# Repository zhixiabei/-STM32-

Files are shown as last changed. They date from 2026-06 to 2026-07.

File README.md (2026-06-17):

# 基于STM32的自动售货机

> **Auto Dealer Based on STM32** — 基于 STM32F103C8T6 的智能自动售货机，支持本地按键操控与 OneNET 云端远程控制。







---

## 📖 目录

- [项目简介](#项目简介)
- [功能特性](#功能特性)
- [硬件架构](#硬件架构)
- [系统框图](#系统框图)
- [引脚分配](#引脚分配)
- [固件说明](#固件说明)
- [快速开始](#快速开始)
- [目录结构](#目录结构)
- [物料清单](#物料清单)
- [PCB与Gerber](#pcb与gerber)
- [云平台配置](#云平台配置)
- [注意事项](#注意事项)

---

## 项目简介

本项目实现了一台基于 STM32F103C8T6 的智能自动售货机。用户可以通过 **本地按键** 浏览商品、选择数量并购买，也可以通过 **OneNET 云平台** 远程下发出货指令。OLED 屏幕实时显示商品信息、温湿度等数据，并通过 MQTT 协议将状态上传至云端。

本项目包含完整的 **固件源码**、**电路原理图**、**PCB 设计** 和 **Gerber 生产文件**，可直接复现。

---

## 功能特性

| 功能模块 | 说明 |
|---|---|
| 🛒 **商品售卖** | 支持 4 通道商品（苹果/香蕉/橙子/芒果），本地按键 + 云端远程双模式控制 |
| 📺 **OLED 显示** | 0.96 寸 SSD1306 OLED，128×64 分辨率，中文界面，显示商品列表/库存/价格 |
| 🌡️ **环境监测** | DHT11 温湿度传感器，实时显示温湿度，超阈值蜂鸣器报警（温度>30°C 或湿度>90%） |
| 🌐 **WiFi 联网** | ESP8266-01S 模块，MQTT 协议连接 OneNET Studio 云平台 |
| ☁️ **云端控制** | 支持 OneNET 命令下发远程出货，定时上报库存/温湿度数据 |
| 🔊 **声光指示** | 8 路 LED 指示灯 + 有源蜂鸣器报警 |
| 🛡️ **库存管理** | 实时跟踪商品库存，售罄后自动锁定 |

---

## 硬件架构

- **主控**: STM32F103C8T6（Cortex-M3, 72MHz, 64KB Flash, 20KB SRAM）
- **显示**: 0.96" OLED SSD1306（I2C，4Pin）
- **通信**: ESP8266-01S（UART1, 115200bps，MQTT 协议）
- **传感器**: DHT11 数字温湿度传感器（单总线）
- **驱动**: L298N 双H桥驱动直流减速电机（正转出货）
- **输入**: 6 键独立按键（上翻/下翻/确认/返回/购物车+/购物车-）
- **输出**: 8 路 LED（商品/状态指示）+ 有源蜂鸣器
- **电源**: DC 12V 输入 → LM2596 5V → AMS1117 3.3V 三级供电

### 整机接线总览

> 点击图片可放大查看

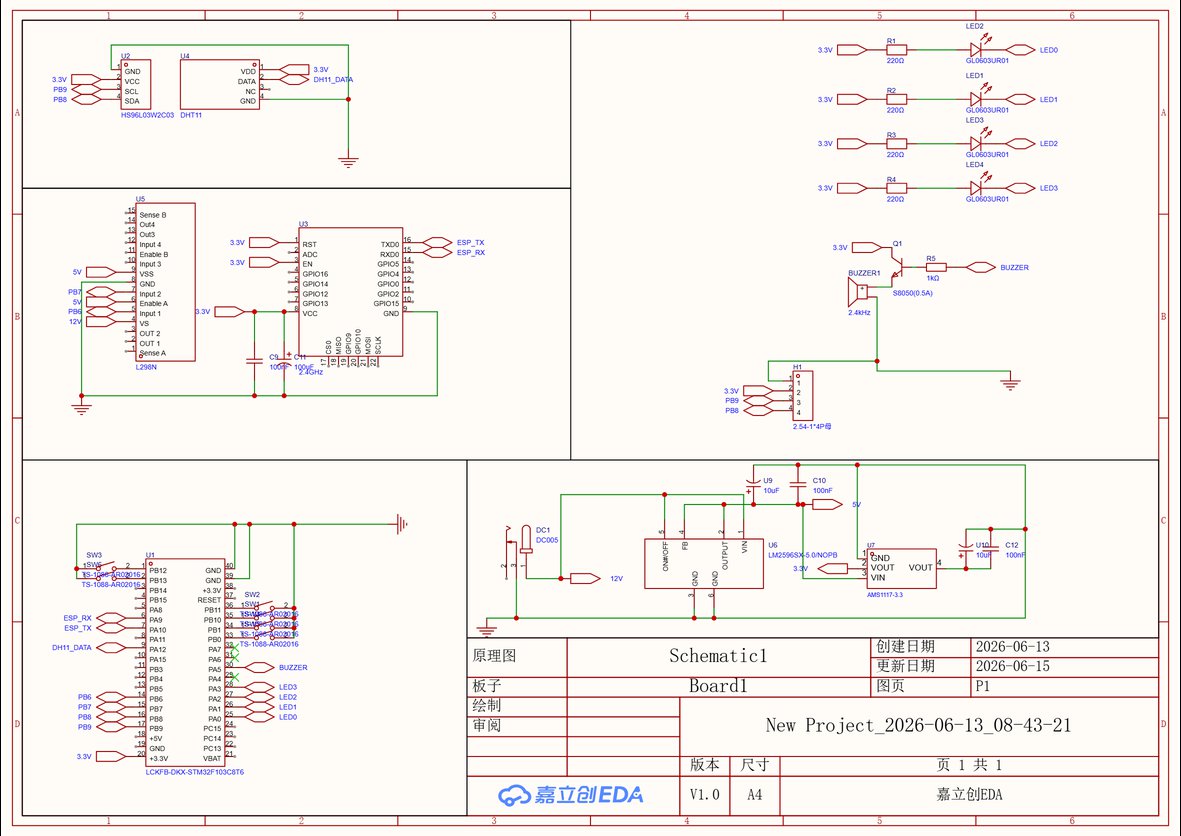
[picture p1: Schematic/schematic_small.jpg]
整机接线总览


---

## 引脚分配

下面是简化的引脚速查表，完整的芯片级引脚对照请参考下方的原理图：

| STM32 引脚 | 功能 | 连接目标 |
|---|---|---|
| PA0 ~ PA7 | GPIO 输出 | LED0 ~ LED7（低电平点亮） |
| PA5 | GPIO 输出 | 蜂鸣器（⚠️ 与 LED5 共用，建议二选一） |
| PA9 | USART1_TX | ESP8266 RXD |
| PA10 | USART1_RX | ESP8266 TXD |
| PA12 | GPIO 输入 | DHT11 DATA（单总线，需 4.7KΩ 上拉） |
| PB0 | GPIO 输入 | 按键 OK（确认） |
| PB1 | GPIO 输入 | 按键 BACK（返回） |
| PB6 | GPIO 输出 | L298N IN1（电机正转） |
| PB7 | GPIO 输出 | L298N IN2（电机反转） |
| PB8 | GPIO 输出 | OLED SCL（软件 I2C 时钟） |
| PB9 | GPIO 输出 | OLED SDA（软件 I2C 数据） |
| PB10 | GPIO 输入 | 按键 CART+（购物车+） |
| PB11 | GPIO 输入 | 按键 CART-（购物车-） |
| PB12 | GPIO 输入 | 按键 UP（上翻） |
| PB13 | GPIO 输入 | 按键 DOWN（下翻） |

> 📖 完整的芯片引脚对照表（含电源/晶振/BOOT/SWD 等全部 48 脚）及原理图设计文档请参阅 **[schematic.md](Auto-Dealer-Based-On-STM32-main/schematic.md)**。

---

## 固件说明

### 开发环境

- **IDE**: Keil MDK 5（或兼容版本）
- **工具链**: Arm Compiler 5 / 6
- **固件库**: STM32F10x 标准外设库 (StdPeriph_Lib)
- **烧录工具**: ST-Link / J-Link（SWD 接口）

### 工程结构

```
Auto-Dealer-Based-On-STM32-main/
├── User/                  # 用户应用层
│   ├── main.c             # 主程序入口，UI 界面与主循环
│   ├── stm32f10x_it.c/h   # 中断服务程序
│   └── stm32f10x_conf.h   # 外设库配置文件
├── Hardware/              # 外设驱动层
│   ├── OLED.c/h           # SSD1306 OLED 驱动（软件 I2C）
│   ├── OLED_Font.h        # 中文字库
│   ├── ESP8266.c/h        # ESP8266 AT 指令 + MQTT 驱动
│   ├── DHT11.c/h          # DHT11 单总线驱动
│   ├── KEY.c/h            # 按键扫描驱动
│   ├── LED.c/h            # LED 驱动
│   ├── BEEP.c/h           # 蜂鸣器驱动
│   ├── ADC.c/h            # ADC 驱动
│   └── Serial.c/h         # 串口驱动
├── System/                # 系统层
│   ├── Delay.c/h          # 延时函数
│   ├── DMA.c/h            # DMA 配置
│   ├── Upload.c/h         # 定时上传 + TIM3 中断
│   ├── i2c.c/h            # 软件 I2C 实现
│   └── main.h             # 系统头文件
├── Start/                 # 启动文件
│   ├── core_cm3.c/h       # Cortex-M3 内核
│   ├── system_stm32f10x.c/h  # 系统时钟配置
│   └── stm32f10x.h        # 外设寄存器定义
├── Library/               # STM32F10x 标准外设库
│   └── stm32f10x_*.c/h    # GPIO/USART/TIM/SPI/I2C/ADC 等
└── 2.1.uvprojx             # Keil MDK 工程文件
```

### 关键逻辑

- **主循环** (`main.c`): 状态机模式，`x` 变量控制界面切换
  - `x=0`: 首页（显示温湿度 + 系统状态）
  - `x=1`: 商品列表页（上下翻选商品）
  - `x=2`: 购物车页（确认数量）
  - `x=4`: 出货中（电机转动 2.5 秒）
- **云端命令**: ESP8266 通过 MQTT 订阅 `DISPENSE_0/2/4/6` 命令，收到后自动进入出货流程
- **定时上报**: TIM3 每 5 秒触发中断 → `DataUpload()` 将温湿度/库存通过 MQTT 上传至 OneNET

---

## 快速开始

### 1. 硬件准备

按照 [原理图文档](Auto-Dealer-Based-On-STM32-main/schematic.md) 中的接线表连接各模块。确保：
- STM32 最小系统板正常工作
- OLED、ESP8266、DHT11 正确接线
- 电源三级供电（12V → 5V → 3.3V）正常

### 2. 固件编译

1. 使用 Keil MDK 打开 `Auto-Dealer-Based-On-STM32-main/2.1.uvprojx`
2. 检查 `ESP8266.c` 中的 WiFi 和 OneNET 配置是否正确
3. 编译工程（Project → Build Target）
4. 通过 SWD 烧录到目标板

### 3. WiFi & OneNET 配置

在 `Hardware/ESP8266.c` 中修改以下参数：

```c
/* WiFi 配置 */
const char* WIFI_SSID     = "你的WiFi名称";
const char* WIFI_PASSWORD = "你的WiFi密码";

/* OneNET Studio MQTT 配置 */
const char* ProductID  = "你的产品ID";
const char* DeviceName = "你的设备名称";
const char* DeviceKey  = "你的设备密钥";
```

### 4. 运行

上电后：
- OLED 显示 "Connect Wi-Fi"，等待 WiFi 连接
- 连接成功后自动连接 OneNET MQTT
- 首页显示温湿度和系统状态
- 通过按键或云端指令操作

### 5. PCB 打板

`Gerber/` 目录包含完整的生产文件，可直接提交给 PCB 厂商（如嘉立创）进行打板。详细说明参见 `Gerber/PCB下单必读.txt`。

---

## 目录结构

```
基于STM32的自动售货机/
├── README.md                              # 项目说明（本文件）
├── .gitignore                             # Git 忽略规则
├── LICENSE                                # 开源协议
├── Auto-Dealer-Based-On-STM32-main/       # 固件源码（Keil MDK 工程）
│   ├── User/                              #   用户层代码
│   ├── Hardware/                          #   外设驱动
│   ├── System/                            #   系统层
│   ├── Start/                             #   启动文件
│   ├── Library/                           #   STM32 标准外设库
│   ├── Objects/                           #   编译输出（含 .hex 固件）
│   ├── Listings/                          #   链接 Map 文件
│   ├── schematic.md                       #   原理图设计文档
│   └── 2.1.uvprojx                        #   Keil 工程文件
├── Schematic/                             # 原理图图片
│   └── schematic_small.jpg                #   原理图预览
├── PCB/                                   # PCB 设计文件
│   ├── New Project_*.epru                 #   立创EDA 工程文件
│   ├── project2.json                      #   工程配置
│   └── IMAGE/                             #   PCB 预览图（待补充）
├── Gerber/                                # PCB 生产文件（可直接打板）
│   ├── Gerber_TopLayer.GTL                #   顶层铜皮
│   ├── Gerber_BottomLayer.GBL             #   底层铜皮
│   ├── Gerber_TopSilkscreenLayer.GTO      #   顶层丝印
│   ├── Gerber_TopSolderMaskLayer.GTS      #   顶层阻焊
│   ├── Gerber_BottomSolderMaskLayer.GBS   #   底层阻焊
│   ├── Gerber_BoardOutlineLayer.GKO       #   板框
│   ├── Gerber_DrillDrawingLayer.GDD       #   钻孔图
│   ├── Drill_PTH_Through.DRL              #   钻孔文件
│   └── PCB下单必读.txt                    #   打板说明
└── Docs/                                  # 文档
    └── BOM_Board1_PCB1.xlsx              #   BOM 物料清单
```

---

## 物料清单

| 类别 | 关键物料 | 数量 | 备注 |
|---|---|---|---|
| 主控 | STM32F103C8T6 最小系统板 | 1 | LQFP-48 |
| 显示 | 0.96" OLED SSD1306 I2C | 1 | 128×64, 蓝色/白色 |
| WiFi | ESP8266-01S | 1 | 8Pin 排针 |
| 传感器 | DHT11 温湿度模块 | 1 | 单总线 |
| 电机驱动 | L298N 模块 | 1 | 双H桥 |
| 电机 | 直流减速电机 12V ~200RPM | 1 | |
| 电源 | LM2596 DC-DC 降压模块 | 1 | 12V→5V |
| 电源 | AMS1117-3.3 LDO | 1 | 5V→3.3V |
| 按键 | 6×6mm 轻触开关 | 6 | |
| LED | 0805 贴片 LED（红/绿/黄） | 8 | 含限流电阻 220Ω |
| 蜂鸣器 | 有源蜂鸣器 3.3V | 1 | |
| 电源 | DC 12V/2A 适配器 | 1 | 5.5×2.1mm |

> 完整 BOM 参见 `Docs/BOM_Board1_PCB1.xlsx`

---

## PCB与Gerber

PCB 使用 **立创EDA** 设计，Gerber 文件已导出，可直接提交打板：

- **Gerber 文件**: `Gerber/` 目录包含所有生产层
- **PCB 工程**: `PCB/` 目录包含立创EDA 工程文件（`.epru`）
- **PCB 预览图**: `PCB/IMAGE/`（待补充 2D/3D 渲染图）

### Gerber 文件清单

| 文件 | 说明 |
|---|---|
| `Gerber_TopLayer.GTL` | 顶层铜皮 |
| `Gerber_BottomLayer.GBL` | 底层铜皮 |
| `Gerber_TopSilkscreenLayer.GTO` | 顶层丝印 |
| `Gerber_BottomSilkscreenLayer.GBO` | 底层丝印 |
| `Gerber_TopSolderMaskLayer.GTS` | 顶层阻焊 |
| `Gerber_BottomSolderMaskLayer.GBS` | 底层阻焊 |
| `Gerber_TopPasteMaskLayer.GTP` | 顶层钢网 |
| `Gerber_BoardOutlineLayer.GKO` | 板框 |
| `Gerber_DrillDrawingLayer.GDD` | 钻孔图 |
| `Drill_PTH_Through.DRL` | 通孔钻孔 |
| `Drill_PTH_Through_Via.DRL` | 过孔钻孔 |

---

## 云平台配置

本项目使用 **中国移动 OneNET Studio** 作为物联网云平台。

### MQTT 主题

| 主题 | 方向 | 说明 |
|---|---|---|
| `$sys/{PID}/{Device}/dp/post/json` | 设备→云 | 数据上报（温湿度/库存） |
| `$sys/{PID}/{Device}/cmd/request/+` | 云→设备 | 命令下发订阅 |

### 上报数据格式 (JSON)

```json
{
  "temp": 25.3,
  "humi": 58.2,
  "Apple": 10,
  "Banana": 8,
  "Orange": 10,
  "Mango": 9
}
```

### 下发命令

| 命令 | 说明 |
|---|---|
| `DISPENSE_0` | 出货：苹果（通道0） |
| `DISPENSE_2` | 出货：香蕉（通道2） |
| `DISPENSE_4` | 出货：橙子（通道4） |
| `DISPENSE_6` | 出货：芒果（通道6） |

---

## 注意事项

1. **PA5 引脚冲突**: PA5 同时驱动 LED5 和蜂鸣器，建议在 PCB 上通过跳线或 0Ω 电阻二选一焊接
2. **ESP8266 供电**: ESP8266 峰值电流约 300mA，AMS1117-3.3 需留足余量，建议在 ESP8266 VCC 旁并联 100μF+100nF 电容
3. **共地**: 所有模块（12V/5V/3.3V）的 GND 必须接在一起
4. **WiFi 凭证**: 发布前请清除 `ESP8266.c` 中的 WiFi 密码和 OneNET 密钥，改为占位符
5. **电机干扰**: 直流电机为强干扰源，电机引线应远离信号线（尤其是 DHT11 单总线和 I2C 线）
6. **I2C 上拉**: 确认 OLED 模块板上是否已集成 I2C 上拉电阻，若无须外加 4.7KΩ×2 至 3.3V
7. **SWD 调试口**: 务必预留 SWDIO(PA13)、SWCLK(PA14)、3.3V、GND 四线调试接口

---

## 许可证

本项目采用 [MIT License](LICENSE) 开源。

---

> **相关文档**: 
> - [原理图设计文档](Auto-Dealer-Based-On-STM32-main/schematic.md)
> - [快速接线参考](Auto-Dealer-Based-On-STM32-main/schematic.md#附录-快速接线表-焊接参考)
> - [BOM 物料清单](Docs/BOM_Board1_PCB1.xlsx)

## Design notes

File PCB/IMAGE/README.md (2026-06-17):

# PCB 预览图

此处应放置 PCB 的 2D/3D 渲染预览图，建议从立创EDA导出以下视角：

- **Top View** — PCB 顶层 3D 视图
- **Bottom View** — PCB 底层 3D 视图
- **Top Silkscreen** — 顶层丝印图

> 在立创EDA中：文件 → 导出 → PNG，选择对应图层即可导出预览图。

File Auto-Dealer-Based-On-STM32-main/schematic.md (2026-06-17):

# 基于STM32的自动售货机 — 原理图设计文档

> **MCU**: STM32F103C8T6 | **固件仓库**: Auto-Dealer-Based-On-STM32  
> **设计工具**: 本原理图适配 立创EDA / Altium Designer / KiCad 均可复现

---

## 目录

1. [系统总体框图](#1-系统总体框图)
2. [STM32F103C8T6 最小系统](#2-stm32f103c8t6-最小系统)
3. [电源电路](#3-电源电路)
4. [OLED 显示接口](#4-oled-显示接口)
5. [ESP8266 WiFi 模块接口](#5-esp8266-wifi-模块接口)
6. [DHT11 温湿度传感器](#6-dht11-温湿度传感器)
7. [按键输入电路](#7-按键输入电路)
8. [LED 指示电路](#8-led-指示电路)
9. [蜂鸣器驱动电路](#9-蜂鸣器驱动电路)
10. [电机驱动电路 (L298N)](#10-电机驱动电路-l298n)
11. [完整引脚对照表](#11-完整引脚对照表)
12. [整机互联拓扑图](#12-整机互联拓扑图)
13. [BOM 物料清单](#13-bom-物料清单)
14. [接线注意事项](#14-接线注意事项)

---

## 1. 系统总体框图

```mermaid
flowchart TB
    subgraph Power["电源系统"]
        DC12V["DC 12V 输入<br/>(适配器/电池)"]
        BUCK5V["LM2596 降压模块<br/>12V → 5V"]
        LDO33["AMS1117-3.3<br/>5V → 3.3V"]
        DC12V --> BUCK5V --> LDO33
    end

    subgraph MCU["主控"]
        STM32["STM32F103C8T6<br/>Cortex-M3, 72MHz<br/>64KB Flash, 20KB SRAM"]
    end

    subgraph Input["输入设备"]
        KEYS["6键独立按键<br/>(上/下/确认/返回/购物车+/购物车-)"]
        DHT11["DHT11<br/>温湿度传感器"]
    end

    subgraph Output["输出设备"]
        OLED["0.96寸 OLED<br/>128x64, I2C, SSD1306"]
        LED8["8路 LED 指示灯<br/>(含蜂鸣器共用)"]
        BUZZER["有源蜂鸣器<br/>3.3V 驱动"]
        MOTOR["直流减速电机<br/>+ L298N 驱动"]
    end

    subgraph Comm["通信"]
        ESP8266["ESP8266-01S<br/>WiFi 模块<br/>连接 OneNet 云平台"]
    end

    LDO33 --> STM32
    BUCK5V --> MOTOR
    LDO33 --> OLED
    LDO33 --> ESP8266
    LDO33 --> DHT11
    LDO33 --> LED8
    LDO33 --> BUZZER

    KEYS -->|"PB0,PB1,PB10~PB13"| STM32
    DHT11 -->|"PA12 (单总线)"| STM32
    STM32 -->|"PB8,PB9 (I2C)"| OLED
    STM32 -->|"PA0~PA7"| LED8
    STM32 -->|"PA5"| BUZZER
    STM32 -->|"PB6,PB7"| MOTOR
    STM32 -->|"PA9,PA10 (UART1)"| ESP8266
```

---

## 2. STM32F103C8T6 最小系统

### 2.1 原理图

```
                          STM32F103C8T6 (LQFP-48)
                    ┌─────────────────────────────────┐
                    │                                 │
               VBAT │1                          48 VDD│──┼── +3.3V
                    │                           47 VSS│──┼── GND
              PC13  │2                          46 PB9│──┼── OLED_SDA (I2C)
         OSC32_IN   │3  PC14                 45 PB8│──┼── OLED_SCL (I2C)
         OSC32_OUT  │4  PC15                 44 PB7│──┼── MOTOR_B
                    │5  PA0  LED0           43 PB6│──┼── MOTOR_A
                    │6  PA1  LED1           42 PB5│
                    │7  PA2  LED2           41 PB4│
                    │8  PA3  LED3           40 PB3│
                    │9  PA4  LED4           39 PB2│
                    │10 PA5  BEEP/LED5      38 PB1│──┼── KEY_BACK
                    │11 PA6  LED6           37 PB0│──┼── KEY_OK
                    │12 PA7  LED7           36 PA15│
           NRST ────│13                    35 PA12│──┼── DHT11_DATA
                    │14 VSS          34 PA11│
              +3.3V │15 VDD          33 PA10│──┼── USART1_RX (ESP TX)
                    │16 PA8            32 PA9│──┼── USART1_TX (ESP RX)
           BOOT0 ── │17 PB15         31 PA8│
           BOOT1 ── │18 PB14         30 PB13│──┼── KEY_DOWN
                    │19 PB13 KEY_DOWN     29 PB12│──┼── KEY_UP
                    │20 PB12 KEY_UP       28 VDD│──┼── +3.3V
                    │21 VSS                      27 VSS│──┼── GND
                    │22 VDD          26 PB11│──┼── KEY_CART-
                    │23 PB10 KEY_CART+     25 PB10│──┼── (reserved)
                    │24 PB11 KEY_CART-               │
                    │                                 │
                    └─────────────────────────────────┘

        晶振电路:                         复位电路:
        ┌─────────────┐                 ┌─────────────┐
        │  OSC_IN  OSC_OUT │                 +3.3V
        │   │        │    │                   │
        │   ├─[8MHz]─┤    │                  [10KΩ]
        │   │        │    │                   │
        │  ─┴─      ─┴─   │              NRST ├──── [100nF] ──── GND
        │ [22pF]   [22pF]  │                   │
        │  ─┬─      ─┬─   │                  ╱ ╲  (复位按键)
        │   │        │    │                 ╱ ○ ╲
        │  GND      GND   │                 ╲   ╱
        └─────────────┘                 ╲ ╱
                                            │
                                           GND
    ```

### 2.2 元件参数

| 元件 | 参数 | 数量 | 说明 |
|---|---|---|---|
| 主控芯片 | STM32F103C8T6 | 1 | LQFP-48 封装 |
| 主晶振 | 8MHz 无源晶振 | 1 | 配 22pF 负载电容 ×2 |
| RTC晶振(可选) | 32.768kHz | 1 | 配 10pF 负载电容 ×2 |
| 复位电阻 | 10KΩ 0603 | 1 | 上拉至 3.3V |
| 复位电容 | 100nF 0603 | 1 | 对地去抖 |
| 复位按键 | 6×6mm 轻触开关 | 1 | 低电平复位 |
| 去耦电容 | 100nF 0603 | 4 | 每个 VDD 引脚各1个 |
| 滤波电容 | 10μF 钽电容 | 1 | VDD 总滤波 |
| BOOT0 跳线 | 2.54mm 排针+跳线帽 | 1 | 默认接 GND |
| BOOT1 跳线 | 2.54mm 排针+跳线帽 | 1 | 默认接 GND |
| SWD调试口 | 4Pin 2.54mm 排针 | 1 | SWDIO/SWCLK/3.3V/GND |

---

## 3. 电源电路

### 3.1 原理图

```
        Power Tree (电源树)
        ═══════════════════════════════════════

        DC 12V 输入                        DC 5V 输出                    DC 3.3V 输出
    (适配器 12V/2A)                  (供 L298N 逻辑 + 外设)        (供 STM32/ESP8266/OLED/DHT11)

    ╔══════════════╗       ╔══════════════╗       ╔══════════════╗
    ║  DC Jack     ║       ║  LM2596      ║       ║  AMS1117-3.3 ║
    ║  5.5×2.1mm   ║──────→║  Buck 模块    ║──────→║  LDO 模块     ║───→ +3.3V
    ║              ║       ║  12V → 5V    ║       ║  5V → 3.3V   ║
    ╚══════════════╝       ╚══════════════╝       ╚══════════════╝
           │                      │                        │
           │ +12V                 │ +5V                    │ +3.3V
           ├──→ L298N 电机电源     ├──→ USB母座(调试)       ├──→ STM32 VDD
           │                      ├──→ 散热风扇(可选)      ├──→ OLED VCC
           │                      │                        ├──→ ESP8266 VCC
           │                      │                        ├──→ DHT11 VCC
           │                      │                        ├──→ LED 阳极电源
           │                      │                        └──→ 蜂鸣器

        ┌─────────────────────────────────────────────────────────┐
        │                   LM2596 模块 (降压)                      │
        │                                                         │
        │   +12V ────┬── LM2596-5.0 ──┬─── +5V                   │
        │            │    IN    OUT   │                            │
        │            │    GND   FB   │                            │
        │            │     │     │    │                            │
        │           ===  100μF   ─┴─ L1 33μH                      │
        │           GND   35V    ─┬─                              │
        │                        ─┴─ 220μF 16V                    │
        │                         │                               │
        │           SS34 续流二极管 (从 OUT 到 GND，反接)           │
        │                                                         │
        └─────────────────────────────────────────────────────────┘

        ┌─────────────────────────────────────────────────────────┐
        │                  AMS1117-3.3 模块 (LDO)                  │
        │                                                         │
        │   +5V ─────┬── AMS1117-3.3 ──┬─── +3.3V                │
        │            │   IN      OUT  │                           │
        │            │   GND(TAB)     │                           │
        │            │     │          │                           │
        │           ===  10μF        === 10μF                     │
        │           GND  钽电容       GND 钽电容                   │
        │            │              │                             │
        │           GND            GND                            │
        └─────────────────────────────────────────────────────────┘

        ┌─────────────────────────────────────────────────────────┐
        │               12V→5V→3.3V 供电汇总                       │
        │                                                         │
        │  【12V 轨】─ L298N 电机驱动 (VMOT，峰值 2A)               │
        │  【5V 轨】 ─ L298N 逻辑供电 (VSS，~50mA)                  │
        │             ─ AMS1117 输入端                             │
        │  【3.3V轨】─ STM32F103C8T6 (~50mA)                       │
        │             ─ ESP8266-01S (峰值 ~300mA，平均 ~80mA)       │
        │             ─ OLED SSD1306 (~20mA)                       │
        │             ─ DHT11 (~2.5mA)                             │
        │             ─ 8×LED (~5mA×8=40mA)                        │
        │             ─ 有源蜂鸣器 (~30mA)                          │
        │                                                         │
        │  3.3V 总电流估算: ~442mA (建议提供 ≥800mA 余量)           │
        │  5V 总电流估算:   ~500mA (建议 LM2596 1A 以上)            │
        └─────────────────────────────────────────────────────────┘
```

### 3.2 元件参数

| 元件 | 参数 | 数量 | 封装 |
|---|---|---|---|
| DC 电源插座 | 5.5×2.1mm DC Jack | 1 | 直插 |
| LM2596 降压模块 | 12V→5V, 3A | 1 | 成品模块 |
| AMS1117-3.3 | 3.3V LDO, 1A | 1 | SOT-223 |
| 输入电容 (12V) | 100μF/35V 铝电解 | 1 | 直插 |
| 输出电容 (5V) | 220μF/16V 铝电解 | 1 | 直插 |
| 输入电容 (AMS1117) | 10μF 钽电容 | 1 | 1206 |
| 输出电容 (AMS1117) | 10μF 钽电容 | 1 | 1206 |
| 续流二极管 | SS34 (肖特基 3A/40V) | 1 | SMC |
| 电源开关 | 自锁开关 KCD1-101 | 1 | 面板安装 |
| 电源指示灯 | 红色 LED + 1KΩ 限流电阻 | 1 | 5mm LED |
| 去耦电容 (3.3V总线) | 100nF 0603 | 6 | 0603 |

---

## 4. OLED 显示接口

### 4.1 原理图

```
              STM32F103C8T6                          0.96" OLED (SSD1306)
              ┌──────────┐                          ┌────────────────┐
              │          │                          │                │
              │     PB8  │──────────────────────────│ SCL            │
              │  (SCL)   │       I2C Clock          │                │
              │     PB9  │──────────────────────────│ SDA            │
              │  (SDA)   │       I2C Data           │                │
              │          │                          │                │
              │          │                          │ VCC ─── +3.3V  │
              │          │                          │ GND ─── GND    │
              │          │                          │                │
              └──────────┘                          └────────────────┘

        I2C 上拉电阻 (如果 OLED 模块板上已有可省略):

                 +3.3V                      +3.3V
                   │                          │
                 [4.7KΩ]                    [4.7KΩ]
                   │                          │
        PB8(SCL)──┼──────── OLED SCL         ┼── PB9(SDA) ── OLED SDA

        OLED 模块规格:
        ┌──────────────────────────────────────────┐
        │  尺寸:      0.96 英寸                      │
        │  分辨率:    128 × 64 像素                  │
        │  驱动芯片:  SSD1306                        │
        │  接口:      I2C (地址 0x3C)                │
        │  工作电压:  3.3V                           │
        │  引脚排列:  VCC/GND/SCL/SDA (4 Pin)        │
        │  颜色:      白色/蓝色双色可选               │
        └──────────────────────────────────────────┘
```

### 4.2 连接

| OLED 模块引脚 | 连接目标 | 备注 |
|---|---|---|
| VCC | +3.3V | |
| GND | GND | |
| SCL | STM32 PB8 | 软件 I2C 时钟 |
| SDA | STM32 PB9 | 软件 I2C 数据 |

> **注**: 代码使用软件 I2C 实现，不使用 STM32 硬件 I2C 外设。上拉电阻通常集成在 OLED 模块 PCB 上，若无则需外加 4.7KΩ ×2。

---

## 5. ESP8266 WiFi 模块接口

### 5.1 原理图

```
              STM32F103C8T6                          ESP8266-01S
              ┌──────────┐                         ┌──────────────┐
              │          │                         │              │
              │     PA9  │──┬──────────────────────│ RXD          │
              │ (TX)     │  │     UART TX          │              │
              │    PA10  │──┼──────────────────────│ TXD          │
              │ (RX)     │  │     UART RX          │              │
              │          │  │                      │              │
              │          │  │                      │ VCC ── +3.3V │
              │          │  │                      │ GND ── GND   │
              │          │  │                      │ CH_PD ── +3.3V│ (使能引脚)
              │          │  │                      │ RST  ── +3.3V │ (通过 10KΩ)
              │          │  │                      │              │
              └──────────┘  │                      └──────────────┘
                            │
        ┌───────────────────┴─────────────────────────────────────┐
        │               电平匹配说明                                │
        │                                                         │
        │  STM32 PA9 (TX)  →  3.3V 电平  →  ESP8266 RXD  ✓ 兼容   │
        │  ESP8266 TXD    →  3.3V 电平  →  STM32 PA10 (RX) ✓ 兼容  │
        │                                                         │
        │  ⚠ ESP8266 峰值电流可达 300mA，3.3V LDO 需足够余量         │
        │  ⚠ ESP8266 CH_PD (EN) 必须接高电平才能工作                 │
        │  ⚠ 建议在 ESP8266 VCC 旁并联 100μF 电解电容 + 100nF 陶瓷   │
        └─────────────────────────────────────────────────────────┘

        ESP8266 电源滤波推荐:

            +3.3V ──┬── 100μF/6.3V ──┬── 100nF ──┬── ESP8266 VCC
                    │    电解电容     │   陶瓷     │
                   GND              GND         GND
```

### 5.2 连接

| ESP8266-01S 引脚 | 连接目标 | 备注 |
|---|---|---|
| VCC | +3.3V | 需 ≥300mA 驱动能力 |
| GND | GND | |
| RXD | STM32 PA9 (USART1_TX) | 115200 波特率 |
| TXD | STM32 PA10 (USART1_RX) | 115200 波特率 |
| CH_PD (EN) | +3.3V (通过 10KΩ 上拉) | 必须拉高 |
| RST | +3.3V (通过 10KΩ 上拉) | 外部复位 |
| GPIO0 | 悬空 (或 10KΩ 上拉) | 低电平=下载模式 |
| GPIO2 | 悬空 (或 10KΩ 上拉) | 上电需高电平 |

---

## 6. DHT11 温湿度传感器

### 6.1 原理图

```
              STM32F103C8T6                            DHT11 模块
              ┌──────────┐                          ┌──────────────┐
              │          │                          │              │
              │    PA12  │──────────────────────────│ DATA         │
              │          │       单总线              │              │
              │          │                          │ VCC ── +3.3V │
              │          │                          │ GND ── GND   │
              │          │                          │              │
              └──────────┘                          └──────────────┘

        上拉电阻 (DHT11 模块板上通常已有):

                           +3.3V
                             │
                           [4.7KΩ ~ 10KΩ]
                             │
              PA12 ──────────┼──────── DHT11 DATA

        DHT11 模块规格:
        ┌──────────────────────────────────────────┐
        │  温度范围:   0 ~ 50°C (精度 ±2°C)          │
        │  湿度范围:   20 ~ 90% RH (精度 ±5%RH)       │
        │  采样周期:   ≥1 秒                         │
        │  接口:       单总线 (One-Wire)              │
        │  工作电压:   3.3V ~ 5V                      │
        │  引脚排列:   VCC/DATA/NC/GND 或 VCC/DATA/GND│
        └──────────────────────────────────────────┘
```

### 6.2 连接

| DHT11 引脚 | 连接目标 | 备注 |
|---|---|---|
| VCC | +3.3V | 兼容 3.3V~5V |
| DATA | STM32 PA12 | 单总线，需 4.7KΩ 上拉 |
| GND | GND | |

---

## 7. 按键输入电路

### 7.1 原理图

```
        6 键独立按键电路 (内部上拉, 按下低电平)

                        按键功能映射:

              上翻 (UP)    下翻 (DOWN)
              ┌─────┐     ┌─────┐
              │ PB12│     │ PB13│
              └──┬──┘     └──┬──┘
                 │            │
          ═══════╪════════════╪═══════
                 │            │
              ┌──┴──┐     ┌──┴──┐     ┌─────┐     ┌─────┐
              │ 上  │     │ 下  │     │确认 │     │返回 │
              │商品 │     │商品 │     │(OK) │     │(BACK)│
              └─────┘     └─────┘     └──┬──┘     └──┬──┘
                                        │            │
                                       PB0          PB1

              商品选择界面:              购物车界面:
              PB12 → 上一商品            PB10 → 数量+1
              PB13 → 下一商品            PB11 → 数量-1
              PB0  → 确认选择            PB0  → 确认结算
              PB1  → 返回首页            (超时自动返回)

        每个按键的电路 (以 PB0 为例):

                        +3.3V
                          │
                    内部上拉 (~40KΩ)
                          │
              ┌───────────┼────── TO STM32 PB0
              │           │
              │     ┌─────┴─────┐
              │     │  10KΩ     │  (可选外部上拉,增强抗干扰)
              │     └─────┬─────┘
              │           │
              │     ┌─────┴─────┐
              │     │     ╱ ╲   │
              │     │    ╱ ○ ╲  │  轻触按键 (6×6mm)
              │     │    ╲   ╱  │
              │     │     ╲ ╱   │
              │     └─────┬─────┘
              │           │
              │          GND
              │
              └──── 消抖电容 100nF (可选,PCB布局时预留)

        6键引脚分配:
        ┌──────────┬──────────┬────────────────────────────┐
        │  按键功能 │ STM32引脚 │  操作界面说明               │
        ├──────────┼──────────┼────────────────────────────┤
        │  上翻     │ PB12     │ 商品选择: 上一个商品         │
        │  下翻     │ PB13     │ 商品选择: 下一个商品         │
        │  确认(OK) │ PB0      │ 选择→确认购买→结算          │
        │  返回     │ PB1      │ 返回上一级 / 首页            │
        │  购物车+  │ PB10     │ 购物车: 同商品数量+1         │
        │  购物车-  │ PB11     │ 购物车: 同商品数量-1         │
        └──────────┴──────────┴────────────────────────────┘
```

### 7.2 元件参数

| 元件 | 参数 | 数量 | 封装 |
|---|---|---|---|
| 轻触按键 | 6×6×5mm, 4脚 | 6 | 直插 |
| 外部上拉电阻(可选) | 10KΩ 0603 | 6 | 0603 |
| 消抖电容(可选) | 100nF 0603 | 6 | 0603 |

> **注**: 代码已启用 STM32 内部上拉 (`GPIO_Mode_IPU`)，硬件上拉电阻非必须，但在工业环境建议保留增强抗干扰。

---

## 8. LED 指示电路

### 8.1 原理图

```
        8路 LED 指示灯 (低电平驱动)

                   +3.3V
                     │
              ┌──────┼──────┬──────┬──────┬──────┬──────┬──────┐
              │      │      │      │      │      │      │      │
             [R]    [R]    [R]    [R]    [R]    [R]    [R]    [R]
           220Ω×8  220Ω   220Ω   220Ω   220Ω   220Ω   220Ω   220Ω
              │      │      │      │      │      │      │      │
             LED    LED    LED    LED    LED    LED    LED    LED
            D0(红) D1(绿) D2(黄) D3(绿) D4(红) D5(黄) D6(红) D7(绿)
              │      │      │      │      │      │      │      │
             PA0    PA1    PA2    PA3    PA4    PA5    PA6    PA7
              │      │      │      │      │      │      │      │
              └──────┴──────┴──────┴──────┴──────┴──────┴──────┘
                               STM32 GPIOA

        单路 LED 电路:
                                             LED电流计算:
                 +3.3V                     ─────────────────
                   │                       ILED = (3.3V - Vf) / R
                 [220Ω]                    = (3.3V - 1.8V) / 220Ω
                   │                       = 1.5V / 220Ω
                  ╱▷  LED                  ≈ 6.8mA
                  ╲▷
                   │
                  PAx (GPIO 低电平点亮)

        LED 功能分配:
        ┌──────┬──────┬──────────────────────────────┐
        │ LED  │ 引脚 │ 用途                         │
        ├──────┼──────┼──────────────────────────────┤
        │ LED0 │ PA0  │ 电源/系统状态指示             │
        │ LED1 │ PA1  │ 商品通道1 状态                │
        │ LED2 │ PA2  │ 商品通道2 状态                │
        │ LED3 │ PA3  │ 商品通道3 状态                │
        │ LED4 │ PA4  │ 商品通道4 状态                │
        │ LED5 │ PA5  │ ⚠ 与蜂鸣器共用,二选一         │
        │ LED6 │ PA6  │ 出货状态指示                  │
        │ LED7 │ PA7  │ WiFi连接状态                  │
        └──────┴──────┴──────────────────────────────┘

        ⚠ PA5 冲突说明:
           PA5 同时被 LED5 和 BEEP 初始化。
           如果同时焊接 LED 和蜂鸣器:
           - 蜂鸣器响时,LED5 也会亮
           - LED5 闪烁时,蜂鸣器可能发出微弱噪音
           建议: 二选一焊接,或通过跳线选择
```

### 8.2 元件参数

| 元件 | 参数 | 数量 | 封装 |
|---|---|---|---|
| LED (红色) | 0805 贴片, Vf≈1.8V | 3 | 0805 |
| LED (绿色) | 0805 贴片, Vf≈2.0V | 3 | 0805 |
| LED (黄色) | 0805 贴片, Vf≈1.9V | 2 | 0805 |
| 限流电阻 | 220Ω 0603 | 8 | 0603 |

---

## 9. 蜂鸣器驱动电路

### 9.1 原理图

```
        有源蜂鸣器驱动 (低电平触发)

        ┌─────────────────────────────────────────────────┐
        │                                                 │
        │    +3.3V                                        │
        │      │                                          │
        │    ┌─┴─┐                                        │
        │    │BEEP│  有源蜂鸣器 (内置振荡器,通直流即响)      │
        │    │   │  工作电压: 3V ~ 5V                      │
        │    └─┬─┘  额定电流: ~30mA                        │
        │      │                                          │
        │    ┌─┴─┐                                        │
        │    │ C │  S8050 NPN 三极管 (开关驱动)             │
        │    └─┬─┘  Ic_max = 500mA                        │
        │      │                                          │
        │     E                                           │
        │      │                                          │
        │     GND                                         │
        │                                                 │
        └─────────────────────────────────────────────────┘

        基极驱动:

                    STM32 PA5 ────[1KΩ]──── B (S8050基极)

        ⚠ PA5 同时驱动 BEEP 和 LED5。由于有源蜂鸣器工作电流 ~30mA,
        而 LED 仅需 ~7mA, 建议优先保证蜂鸣器焊接,LED5 通过跳线可选。

        简化的直接驱动方案 (如果蜂鸣器电流小):

                    PA5 ──── 蜂鸣器 ──── GND

        提示: 代码中 Beep_Init() 将 PA5 配置为推挽输出,
        GPIO_SetBits 关闭蜂鸣器(高电平),GPIO_ResetBits 开启(低电平)。
        蜂鸣器负极接 PA5, 正极接 +3.3V。
```

### 9.2 元件参数

| 元件 | 参数 | 数量 | 封装 |
|---|---|---|---|
| 有源蜂鸣器 | 3.3V 电磁式, ≥85dB | 1 | 直插 12mm |
| NPN 三极管 | S8050 (或 2N3904) | 1 | SOT-23 |
| 基极电阻 | 1KΩ 0603 | 1 | 0603 |
| 续流二极管(可选) | 1N4148 (反向并联蜂鸣器) | 1 | SOD-123 |

---

## 10. 电机驱动电路 (L298N)

### 10.1 原理图

```
        直流电机驱动 — L298N 模块

                     ┌───────────────── L298N 模块 ──────────────────┐
                     │                                               │
        +12V ────────┤ VMOT (电机电源, 12V)                           │
                     │                                               │
        +5V ─────────┤ VSS  (逻辑电源, 5V)   OUT1 ────┬── 直流电机    │
                     │                               │   (减速电机)   │
        GND ─────────┤ GND                  OUT2 ────┘               │
                     │                                               │
        STM32 PB6 ───┤ IN1                                    │      │
        STM32 PB7 ───┤ IN2                                          │
                     │                                               │
        悬空/接GND ──┤ ENA (使能, 跳线帽短接=常使能)                  │
        悬空/接GND ──┤ ENB (未使用)                                   │
                     │                                               │
                     └───────────────────────────────────────────────┘

        电机控制逻辑 (L298N):
        ┌──────┬──────┬────────────────┐
        │ IN1  │ IN2  │  电机状态       │
        │(PB6) │(PB7) │                │
        ├──────┼──────┼────────────────┤
        │  0   │  0   │  停止 (刹车)    │
        │  1   │  0   │  正转 (出货)    │
        │  0   │  1   │  反转           │
        │  1   │  1   │  停止 (刹车)    │
        └──────┴──────┴────────────────┘

        代码中 Motor_Turn() 的逻辑:
        ┌───────────────────────────────────────┐
        │  PB6 = 1  (正转启动)                  │
        │  Delay_ms(2500)  — 电机转动 2.5 秒     │
        │  PB6 = 0  (停止)                      │
        │                                       │
        │  实际使用: 电机正转 2.5 秒推出商品      │
        │  然后停止等待下一次触发                 │
        └───────────────────────────────────────┘
```

### 10.2 连接

| L298N 引脚 | 连接目标 | 备注 |
|---|---|---|
| VMOT | DC +12V | 电机供电, 需 ≥1A |
| VSS | DC +5V | 逻辑供电 |
| GND | GND | 需与STM32共地 |
| IN1 | STM32 PB6 | 电机方向控制1 |
| IN2 | STM32 PB7 | 电机方向控制2 |
| ENA | 跳线帽短接至5V (常使能) | 或接PWM调速 |
| ENB | 未使用/悬空 | |
| OUT1 | 直流电机 + | |
| OUT2 | 直流电机 - | |

### 10.3 元件参数

| 元件 | 参数 | 数量 | 说明 |
|---|---|---|---|
| L298N 驱动模块 | 双H桥, 2A/通道 | 1 | 成品模块 |
| 直流减速电机 | 12V, 100~300 RPM | 1 | 扭力视商品重量而定 |
| 续流二极管 | SS34 (L298N 模块已集成) | - | 模块自带 |
| 电机电源滤波电容 | 100μF/25V 铝电解 | 1 | 电机启动去耦 |

---

## 11. 完整引脚对照表

### 11.1 STM32F103C8T6 → 各外设

```
┌────────┬───────────┬──────────────────────┬─────────┬──────────┐
│ 引脚   │ 端口功能  │ 连接目标             │ 模式    │ 备注     │
├────────┼───────────┼──────────────────────┼─────────┼──────────┤
│ PA0    │ GPIO/ADC0 │ LED0 指示灯           │ 推挽输出 │ 低电平点亮│
│ PA1    │ GPIO/ADC1 │ LED1 指示灯           │ 推挽输出 │ 低电平点亮│
│ PA2    │ GPIO/ADC2 │ LED2 指示灯           │ 推挽输出 │ 低电平点亮│
│ PA3    │ GPIO/ADC3 │ LED3 指示灯           │ 推挽输出 │ 低电平点亮│
│ PA4    │ GPIO      │ LED4 指示灯           │ 推挽输出 │ 低电平点亮│
│ PA5    │ GPIO      │ 蜂鸣器 / LED5         │ 推挽输出 │ ⚠共用冲突│
│ PA6    │ GPIO      │ LED6 指示灯           │ 推挽输出 │ 低电平点亮│
│ PA7    │ GPIO      │ LED7 指示灯           │ 推挽输出 │ 低电平点亮│
│ PA9    │ USART1_TX │ ESP8266 RXD           │ 复用推挽 │ 115200bps│
│ PA10   │ USART1_RX │ ESP8266 TXD           │ 上拉输入 │ 115200bps│
│ PA12   │ GPIO      │ DHT11 DATA            │ 上拉输入 │ 单总线   │
│ PB0    │ GPIO      │ 按键: 确认(OK)        │ 上拉输入 │ 按下=0   │
│ PB1    │ GPIO      │ 按键: 返回(BACK)      │ 上拉输入 │ 按下=0   │
│ PB6    │ GPIO      │ L298N IN1 (电机正转)   │ 推挽输出 │          │
│ PB7    │ GPIO      │ L298N IN2 (电机反转)   │ 推挽输出 │          │
│ PB8    │ GPIO      │ OLED SCL (I2C时钟)    │ 推挽输出 │ 软件I2C  │
│ PB9    │ GPIO      │ OLED SDA (I2C数据)    │ 推挽输出 │ 软件I2C  │
│ PB10   │ GPIO      │ 按键: 购物车+         │ 上拉输入 │ 按下=0   │
│ PB11   │ GPIO      │ 按键: 购物车-         │ 上拉输入 │ 按下=0   │
│ PB12   │ GPIO      │ 按键: 上翻 (UP)       │ 上拉输入 │ 按下=0   │
│ PB13   │ GPIO      │ 按键: 下翻 (DOWN)     │ 上拉输入 │ 按下=0   │
├────────┼───────────┼──────────────────────┼─────────┼──────────┤
│ NRST   │ RST       │ 复位电路              │         │          │
│ BOOT0  │ BOOT      │ GND (正常模式)        │         │          │
│ BOOT1  │ BOOT      │ GND (正常模式)        │         │          │
│ OSC_IN │ HSE       │ 8MHz 晶振             │         │          │
│ OSC_OUT│ HSE       │ 8MHz 晶振             │         │          │
│ VDD×4  │ PWR       │ +3.3V                 │         │ 各配100nF│
│ VSS×4  │ PWR       │ GND                   │         │          │
└────────┴───────────┴──────────────────────┴─────────┴──────────┘
```

### 11.2 未使用引脚处理

```
┌─────────┬────────────────────────────────┐
│ 引脚    │ 处理方式                        │
├─────────┼────────────────────────────────┤
│ PA8     │ 悬空 (或 10KΩ 下拉)             │
│ PA11    │ 悬空                            │
│ PA13    │ SWDIO (调试口,预留)             │
│ PA14    │ SWCLK (调试口,预留)             │
│ PA15    │ 悬空                            │
│ PB2     │ 悬空                            │
│ PB3     │ 悬空 (或预留 JTAG)              │
│ PB4     │ 悬空 (或预留 JTAG)              │
│ PB5     │ 悬空                            │
│ PB14    │ 悬空                            │
│ PB15    │ 悬空                            │
│ PC13    │ 悬空 (或接LED,注意电流限制)      │
│ PC14    │ 悬空 (或 RTC 晶振)              │
│ PC15    │ 悬空 (或 RTC 晶振)              │
└─────────┴────────────────────────────────┘
```

---

## 12. 整机互联拓扑图

```
                         整机接线总览
    ═══════════════════════════════════════════════════════════

                         ┌─────────────────────┐
                    ┌────┤   DC 12V 电源适配器   │
                    │    └─────────────────────┘
                    │              │
                    │         ┌────┴────┐
                    │         │  开关    │
                    │         └────┬────┘
                    │              │
              ┌─────┴──────┐  ┌───┴──────┐
              │  LM2596    │  │  L298N   │
              │  12V→5V    │  │  电机驱动  │
              └─────┬──────┘  └──┬───┬───┘
                    │            │   │
              ┌─────┴──────┐   OUT1 OUT2
              │  AMS1117   │     │   │
              │  5V→3.3V   │   ┌─┴───┴─┐
              └─────┬──────┘   │ 直流  │
                    │          │ 电机  │
           +3.3V 总线          └───────┘
              │
    ┌─────────┼─────────┬─────────┬─────────┬─────────┐
    │         │         │         │         │         │
 ┌──┴──┐  ┌──┴──┐  ┌──┴──┐  ┌──┴──┐  ┌──┴──┐  ┌──┴──┐
 │8LED │  │蜂鸣器│  │OLED │  │ESP  │  │DHT11│  │按键 │
 │模块 │  │     │  │0.96"│  │8266 │  │传感器│  │×6   │
 └──┬──┘  └──┬──┘  └──┬──┘  └──┬──┘  └──┬──┘  └──┬──┘
    │        │        │        │        │        │
    └────────┼────────┼────────┼────────┼────────┘
             │        │        │        │
        PA0~PA7  PA5   PB8,PB9 PA9,PA10 PA12  PB0,PB1,PB10~PB13
             │        │        │        │        │
             └────────┴────────┴────────┴────────┘
                            │
                   ┌────────┴────────┐
                   │ STM32F103C8T6    │
                   │ (最小系统板)      │
                   └─────────────────┘
```

---

## 13. BOM 物料清单

### 13.1 核心元件

| 序号 | 元件 | 型号/参数 | 数量 | 封装 | 备注 |
|---|---|---|---|---|---|
| 1 | MCU | STM32F103C8T6 | 1 | LQFP-48 | 或最小系统板 |
| 2 | OLED 显示屏 | 0.96寸 SSD1306 I2C | 1 | 模块 | 4Pin 蓝色/白色 |
| 3 | WiFi 模块 | ESP8266-01S | 1 | 模块 | 8Pin 排针 |
| 4 | 温湿度传感器 | DHT11 | 1 | 模块 | 3Pin/4Pin |
| 5 | 电机驱动 | L298N 模块 | 1 | 模块 | 双H桥 |
| 6 | 直流减速电机 | 12V 200RPM | 1 | - | 带减速箱 |

### 13.2 电源

| 序号 | 元件 | 型号/参数 | 数量 | 封装 | 备注 |
|---|---|---|---|---|---|
| 7 | 降压模块 | LM2596 DC-DC 12V→5V 3A | 1 | 模块 | 成品模块 |
| 8 | LDO | AMS1117-3.3 SOT-223 | 1 | SOT-223 | 或集成于最小系统板 |
| 9 | DC 电源插座 | DC-005 5.5×2.1mm | 1 | 直插 | 母座 |
| 10 | 12V 电源适配器 | 12V/2A | 1 | - | DC 5.5×2.1mm 公头 |
| 11 | 电源开关 | KCD1-101 船型开关 | 1 | 面板 | 自锁 |
| 12 | 电解电容 | 100μF/35V | 1 | 直插 8mm | 输入滤波 |
| 13 | 电解电容 | 220μF/16V | 1 | 直插 8mm | 输出滤波 |
| 14 | 电解电容 | 100μF/6.3V | 1 | 直插 6mm | ESP8266 去耦 |
| 15 | 钽电容 | 10μF/16V | 2 | 1206 | AMS1117 输入/输出 |
| 16 | 肖特基二极管 | SS34 | 1 | SMC | 续流 |
| 17 | 陶瓷电容 | 100nF | 10 | 0603 | 各处去耦 |

### 13.3 输入/输出

| 序号 | 元件 | 型号/参数 | 数量 | 封装 | 备注 |
|---|---|---|---|---|---|
| 18 | 轻触按键 | 6×6×5mm | 6 | 直插 | PB0/1/10/11/12/13 |
| 19 | LED 红色 | 0805 Vf=1.8V | 3 | 0805 | |
| 20 | LED 绿色 | 0805 Vf=2.0V | 3 | 0805 | |
| 21 | LED 黄色 | 0805 Vf=1.9V | 2 | 0805 | |
| 22 | 限流电阻 | 220Ω ±5% | 8 | 0603 | LED 限流 |
| 23 | 有源蜂鸣器 | 3.3V ≥85dB | 1 | 直插 12mm | |
| 24 | NPN 三极管 | S8050 | 1 | SOT-23 | 蜂鸣器驱动 |

### 13.4 无源元件

| 序号 | 元件 | 型号/参数 | 数量 | 封装 | 备注 |
|---|---|---|---|---|---|
| 25 | 8MHz 无源晶振 | ±20ppm | 1 | 49S 或 3225 | |
| 26 | 22pF 电容 | NPO/COG | 2 | 0603 | 晶振负载电容 |
| 27 | 10KΩ 电阻 | ±5% | 8 | 0603 | 上拉/复位/BOOT |
| 28 | 1KΩ 电阻 | ±5% | 1 | 0603 | 蜂鸣器基极 |
| 29 | 4.7KΩ 电阻 | ±5% | 2 | 0603 | I2C上拉(备用) |
| 30 | 排针 | 2.54mm 单排 | 若干 | - | 模块连接 |
| 31 | 跳线帽 | 2.54mm | 3 | - | BOOT/EAN |
| 32 | 杜邦线 | 母对母 20cm | 30+ | - | 模块互联 |

---

## 14. 接线注意事项

### 14.1 电源

1. **12V 与 5V/3.3V 隔离**: 12V 仅供给 L298N 电机驱动和 LM2596 输入端，不要直接接入 STM32 或 ESP8266。
2. **ESP8266 供电**: ESP8266 瞬时电流可达 300mA, AMS1117-3.3 需提供足够余量。建议在 ESP8266 VCC 引脚旁并联 100μF 电解电容 + 100nF 陶瓷电容。
3. **共地**: 所有模块的 GND 必须连接在一起（12V、5V、3.3V 的 GND 共地）。
4. **上电顺序**: 先上电 12V → LM2596 输出 5V → AMS1117 输出 3.3V。断电：先断 12V。

### 14.2 信号

5. **PA5 冲突处理**: PA5 同时用于 LED5 和蜂鸣器。建议在 PCB 设计时通过 0Ω 电阻或跳线二选一：
   - 短接 R_BEEP → 蜂鸣器功能
   - 短接 R_LED5 → LED5 功能
   - 或直接优先焊接蜂鸣器（本项目核心报警功能）
6. **I2C 上拉**: 确认 OLED 模块板上是否有 I2C 上拉电阻。如无，需在 PB8(SCL) 和 PB9(SDA) 各加 4.7KΩ 上拉至 3.3V。
7. **按键消抖**: 代码中已实现 20ms 软件消抖。硬件上如需增强抗干扰，每个按键并联 100nF 电容到 GND。
8. **UART 连接**: STM32 TX(PA9) → ESP8266 RX, STM32 RX(PA10) → ESP8266 TX，注意**交叉连接**（非直连）。

### 14.3 布局

9. **散热**: L298N 模块工作时会发热，建议安装在通风良好处。大电流工作时需加装散热片。
10. **天线区域**: ESP8266 模块的 PCB 天线区域不要覆铜，远离金属物体和大面积 GND 铺铜，以保证 WiFi 信号。
11. **电机干扰**: 直流电机是强干扰源，电机引线应远离信号线（特别是 DHT11 单总线和 I2C 线）。电机两端建议并联 104 瓷片电容吸收火花干扰。
12. **SWD 调试口**: 务必预留 SWDIO(PA13)、SWCLK(PA14)、3.3V、GND 四个调试引脚。

---

## 附录: 快速接线表 (焊接参考)

```
STM32 引脚  ────  目标模块引脚
══════════════════════════════════════

PA0  ──── LED0 (经 220Ω → 3.3V)
PA1  ──── LED1 (经 220Ω → 3.3V)
PA2  ──── LED2 (经 220Ω → 3.3V)
PA3  ──── LED3 (经 220Ω → 3.3V)
PA4  ──── LED4 (经 220Ω → 3.3V)
PA5  ──── 蜂鸣器基极 (经 1KΩ → S8050 B极)
            S8050 C极 ← 蜂鸣器 ← 3.3V
            S8050 E极 → GND
PA6  ──── LED6 (经 220Ω → 3.3V)
PA7  ──── LED7 (经 220Ω → 3.3V)
PA9  ──── ESP8266 RXD
PA10 ──── ESP8266 TXD
PA12 ──── DHT11 DATA (另加 4.7KΩ 上拉至 3.3V)
PB0  ──── 按键 OK → GND
PB1  ──── 按键 BACK → GND
PB6  ──── L298N IN1
PB7  ──── L298N IN2
PB8  ──── OLED SCL
PB9  ──── OLED SDA
PB10 ──── 按键 CART+ → GND
PB11 ──── 按键 CART- → GND
PB12 ──── 按键 UP → GND
PB13 ──── 按键 DOWN → GND

3.3V  ──── OLED VCC, ESP8266 VCC/CH_PD, DHT11 VCC
5V   ──── L298N VSS (逻辑供电)
12V  ──── L298N VMOT (电机供电)
GND  ──── 所有模块 GND (共地!)
```

---

> **文档版本**: v1.0  
> **最后更新**: 2026-06-13  
> **对应固件**: Auto-Dealer-Based-On-STM32 (Keil MDK, STM32F10x 标准外设库)

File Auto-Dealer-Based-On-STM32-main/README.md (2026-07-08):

# Auto Dealer Based ON STM32
基于STM32的自动售货机

## 2026-07-07 更新

适配国产STM32F103C8T6芯片，修复烧录、时钟、串口、延时等硬件兼容问题；适配有源蜂鸣器；WiFi/MQTT连接调通，已接入OneNET平台。

## 2026-07-08 更新

新增手机Web下单界面 (`web/mobile.html`)，可通过手机浏览器远程下单。

### 📱 手机下单 — 使用方法

**① 推荐：Python HTTP 服务**
```bash
cd web
python -m http.server 8080
```
手机连接**同一 WiFi**，浏览器打开：`http://<电脑IP>:8080/mobile.html`

**② 直接打开**
将 `web/mobile.html` 发送到手机，用浏览器直接打开即可。

**③ 部署到静态托管**
上传到 GitHub Pages / Netlify 等平台，手机浏览器随时访问。

### ⚙ 配置
页面右下角点 ⚙ 按钮可配置 OneNET 连接参数（已预填项目默认值）。

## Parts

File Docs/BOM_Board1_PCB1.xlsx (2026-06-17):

No. | Quantity | Comment | Designator | Footprint | Value | Manufacturer Part | Manufacturer | Supplier Part | Supplier
1 | 1 | 2.4kHz | BUZZER1 | BUZ-TH_BD12.0-P7.60-D0.6-FD | 2.4kHz | TMB12A05 | 华能 | C96093 | LCSC
2 | 3 | 100nF | C9,C10,C12 | C0603 | 100nF | CL10B104KB8NNNC | SAMSUNG(三星) | C1591 | LCSC
3 | 1 | 100uF | C11 | CAP-SMD_BD5.0-L5.3-W5.3-LS6.0-FD-H5.4 | 100uF | RVT6.3V100M5X5 | JIERR(捷而瑞) | C49233126 | LCSC
4 | 1 | DC005 | DC1 | DC-IN-TH_DC005 |  | DC005 | SHOU HAN(首韩) | C431533 | LCSC
5 | 4 | GL0603UR01 | LED1,LED2,LED3,LED4 | LED0603-FD |  | GL0603UR01 | Guiguang light(桂光光电) | C51933292 | LCSC
6 | 1 | S8050(0.5A) | Q1 | SOT-23-3_L2.9-W1.3-P1.90-LS2.4-BR |  | S8050(0.5A) | EIC | C3014350 | LCSC
7 | 4 | 220Ω | R1,R2,R3,R4 | R0603 | 220Ω | FRC0603J221 TS | FOJAN(富捷) | C2907127 | LCSC
8 | 1 | 1kΩ | R5 | R0603 | 1kΩ | RT0603BRD071KL | YAGEO(国巨) | C110776 | LCSC
9 | 6 | TS-1088-AR02016 | SW1,SW2,SW3,SW4,SW5,SW6 | SW-SMD_L3.9-W3.0-P4.45 |  | TS-1088-AR02016 | XUNPU(讯普) | C720477 | LCSC
10 | 1 | LCKFB-DKX-STM32F103C8T6 | U1 | CONN-TH_L53.3-W22.9_STM32F103C8T6-CARD |  | LCKFB-DKX-STM32F103C8T6 | 立创开发板 | C22396880 | LCSC
11 | 1 | HS96L03W2C03 | U2 | OLED-TH_L27.8-W27.2-P2.54_C9900033791 |  | HS96L03W2C03 | HS(汉昇) | C5248080 | LCSC
12 | 1 | 2.4GHz | U3 | WIFIM-SMD_ESP-12F-ESP8266MOD | 2.4GHz | ESP-12F(ESP8266MOD) | Ai-Thinker(安信可) | C82891 | LCSC
13 | 1 | DHT11 | U4 | SENSOR-TH_DHT11 |  | DHT11 | 广州奥松 | C117051 | LCSC
14 | 1 | L298N | U5 | MULTIWATT-15_L19.6-W5.0-P1.27-L |  | L298N | ST(意法半导体) | C19922 | LCSC
15 | 1 | LM2596SX-5.0/NOPB | U6 | TO-263-5_L10.2-W8.9-P1.70-TL |  | LM2596SX-5.0/NOPB | TI(德州仪器) | C10002 | LCSC
16 | 1 | AMS1117-3.3 | U7 | SOT-223-3_L6.5-W3.4-P2.30-LS7.0-BR |  | AMS1117-3.3 | Advanced Monolithic Systems | C6186 | LCSC
17 | 2 | 10uF | U9,U10 | CAP-SMD_L3.2-W1.6 | 10uF | TMCMA1C106KTRF | VISHAY(威世) | C4988312 | LCSC

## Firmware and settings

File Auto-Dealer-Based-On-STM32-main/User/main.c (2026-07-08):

#include "stm32f10x.h"
#include "OLED.h"
#include "ESP8266.h"
#include "Serial.h"
#include "DHT11.h"
#include "LED.h"
#include "KEY.h"
#include "BEEP.h"
#include "Upload.h"
#include <string.h>
#include <stdio.h>

/* DHT11 全局变量（定义在 DHT11.c） */
extern u8 humi, temp, dechumi, dectemp;

/* ---- 商品数据 ---- */
/* inventory/price: 8 个槽，偶数索引=商品 */
u8 inventory[16] = {10,0, 10,0, 10,0, 10,0,  9,0, 10,0, 10,0, 10,0};
u8 price[16]     = { 2,0,  1,0,  2,0,  3,0,  4,0,  1,0,  1,0,  4,0};

/* ---- 保存库存到 Flash（每次变更后调用）---- */
static void save_inventory(void)
{
    FlashStore_Save(inventory, price);
}

/* ---- 加载库存：优先从 Flash 读取，失败则用默认值 ---- */
static void load_inventory(void)
{
    if (!FlashStore_Load(inventory, price))
    {
        /* Flash 为空或损坏，写入默认值 */
        FlashStore_Save(inventory, price);
    }
}

/* ---- 延时（约等于 ms）---- */
static void dms(volatile u32 ms)
{
    while (ms--) { volatile u32 n = 2000; while (n--) __NOP(); }
}

/* ---- OLED 快捷显示 ---- */
static void show(const char* l1, const char* l2)
{
    OLED_Clear();
    OLED_ShowString(0, 0,  (u8*)l1, 16, 1);
    OLED_ShowString(0, 16, (u8*)l2, 16, 1);
    OLED_Refresh();
}

/* ---- 错误死循环 ---- */
static void die(const char* m)
{
    show("FAIL", m);
    while (1) { __NOP(); }
}

/* 商品名 */
static const char* names[] = {"Apple","Banana","Orange","Mango"};

int main(void)
{
    /* ---- 状态变量 ---- */
    int8_t  page    = 0;    /* 0=主页 1=选商品 2=选数量 4=出货 */
    int8_t  prev    = -1;   /* 上一页，用于判断刷新 */
    int8_t  sel     = 0;    /* 当前选中商品索引 (0,2,4,6,8,10,12,14) */
    int8_t  cnt     = 0;    /* 购买数量 */
    int8_t  remote  = 0;    /* 0=本地按键出货 1=云端远程出货（需回复服务调用） */
    u8      i;
    u16     tick = 0;
    char    buf[32], json[320];

    /* ---- 初始化硬件 ---- */
    OLED_Init();
    OLED_Clear();
    OLED_ShowString(0, 0, "Vending...", 16, 1);
    OLED_Refresh();

    /* 从 Flash 恢复上次的库存数据 */
    load_inventory();

    Key_Init();
    LED_Init();
    DHT11_Init();
    Mortor_Init();
    Beep_Init();

    /* ---- WiFi + MQTT ---- */
    show("WiFi", "init...");
    {
        int r = ESP8266_Init();
        if (r <= 0) {
            sprintf(buf, "ERR=%d", r);
            die(buf);
        }
    }

    show("WiFi+MQTT", "OK!");
    dms(5000);  /* 等 TCP/IP 栈就绪 */

    /* 定时上传 */
    TIM3IT_Init();

    /* 初始化 LED 状态：有货的通道亮灯 */
    LED_UpdateAll(inventory);

    /* ======== 主循环 ======== */
    while (1)
    {
        tick++;

        /* ---- 传感器（关串口中断，防 DHT11 时序被干扰）---- */
        if (tick % 20 == 0) {
            USART_ITConfig(USART1, USART_IT_RXNE, DISABLE);
            DHT11_Read_data((u8*)&humi, (u8*)&temp, &dechumi, &dectemp);
            USART_ITConfig(USART1, USART_IT_RXNE, ENABLE);
        }

        /* ---- 告警：高温 / 高湿 ---- */
        if (temp > 30 || humi > 90)
            BEEP_Alert();

        /* ---- 云端命令 ---- */
        {
            int8_t cmd = ESP8266_CheckCmd();
            if (cmd != -1)
            {
                if (page == 0)
                {
                    if (inventory[cmd] > 0) {
                        sel = cmd;
                        cnt = 1;
                        remote = 1;             /* 遥控出货，需回报结果 */
                        page = 4;
                    } else {
                        /* 库存为零，回复服务调用失败 */
                        ESP8266_ServiceReply(1);
                    }
                }
                else
                {
                    /* 设备忙，无法处理，清除待回复 ID */
                    ESP8266_ClearPendingSvc();
                }
            }
            else
            {
                /* 库存改写: SET_X_N  e.g. SET_0_15 */
                u8 new_qty;
                int8_t idx = ESP8266_ParseInventory(&new_qty);
                if (idx >= 0 && idx < 16) {
                    inventory[idx] = new_qty;
                    LED_UpdateAll(inventory);   /* 云端改库存后刷新 LED */
                    save_inventory();           /* 持久化到 Flash */
                }
                /* OneNET 属性设置: {"params":{"Banana":10}} */
                else if (ESP8266_HandlePropertySet(inventory)) {
                    LED_UpdateAll(inventory);
                    save_inventory();
                }
            }
        }

        /* ---- 按键处理 ---- */
        /* PB12: 上一个 */
        if (GPIO_ReadInputDataBit(GPIOB, GPIO_Pin_12) == 0)
        {
            dms(20); while (GPIO_ReadInputDataBit(GPIOB, GPIO_Pin_12) == 0);
            if (page == 1) { sel += 2; if (sel > 14) sel = 0; }
        }
        /* PB13: 下一个 */
        if (GPIO_ReadInputDataBit(GPIOB, GPIO_Pin_13) == 0)
        {
            dms(20); while (GPIO_ReadInputDataBit(GPIOB, GPIO_Pin_13) == 0);
            if (page == 1) { sel -= 2; if (sel < 0) sel = 14; }
        }
        /* PB1: 返回 / 进入选择 */
        if (GPIO_ReadInputDataBit(GPIOB, GPIO_Pin_1) == 0)
        {
            dms(20); while (GPIO_ReadInputDataBit(GPIOB, GPIO_Pin_1) == 0);
            if (page == 0)      { page = 1; sel = 0; }      /* 进入选择 */
            else if (page == 1) { page = 0; }                /* 返回主页 */
            else if (page == 2) { page = 1; cnt = 0; }       /* 返回选商品 */
        }
        /* PB0: 确认 */
        if (GPIO_ReadInputDataBit(GPIOB, GPIO_Pin_0) == 0)
        {
            dms(20); while (GPIO_ReadInputDataBit(GPIOB, GPIO_Pin_0) == 0);
            if (page == 1 && inventory[sel] > 0)
                { page = 2; cnt = 1; }                       /* 进入选数量 */
            else if (page == 2 && cnt > 0)
                { page = 4; }                                /* 确认购买 */
        }
        /* PB11: 减 */
        if (GPIO_ReadInputDataBit(GPIOB, GPIO_Pin_11) == 0)
        {
            dms(20); while (GPIO_ReadInputDataBit(GPIOB, GPIO_Pin_11) == 0);
            if (page == 2) { if (--cnt < 1) cnt = 1; }
        }
        /* PB10: 加 */
        if (GPIO_ReadInputDataBit(GPIOB, GPIO_Pin_10) == 0)
        {
            dms(20); while (GPIO_ReadInputDataBit(GPIOB, GPIO_Pin_10) == 0);
            if (page == 2 && cnt < inventory[sel]) cnt++;
        }

        /* ---- 界面渲染（仅页面切换时全刷新）---- */
        if (page != prev) {
            prev = page;
            OLED_Clear();

            if (page == 0)
            {
                OLED_ShowString(0,  0, "Temp:",   16, 1);
                OLED_ShowString(0, 16, "Humi:",   16, 1);
                OLED_ShowString(0, 32, "Press K1", 16, 1);
                OLED_ShowString(0, 48, "to buy",   16, 1);
            }
            else if (page == 1)
            {
                /* 商品列表页 —— 只画静态标签 */
            }
            else if (page == 2)
            {
                OLED_ShowString(0,  0, "Item:",   16, 1);
                OLED_ShowString(0, 16, "Count:",  16, 1);
                OLED_ShowString(0, 32, "Total $", 16, 1);
                OLED_ShowString(0, 48, "K0=OK K1=Back", 16, 1);
            }
            else if (page == 4)
            {
                OLED_ShowString(0,  0, "Dispensing...", 16, 1);
                OLED_Refresh();

                /* 1. 先扣库存 + 持久化（业务逻辑不应依赖硬件） */
                inventory[sel] -= cnt;
                LED_UpdateAll(inventory);
                save_inventory();
                upload = 1;              /* 立即上传最新库存到 OneNET */

                /* 2. 云端远程出货（暂不回复服务调用，避免 tcp_send 干扰 MQTT 上传链路） */
                if (remote) {
                    /* ESP8266_ServiceReply(0);  —— 暂屏蔽，防止破坏 MQTT 连接 */
                    remote = 0;
                }

                /* 3. 最后转动电机（硬件动作，放最后不影响业务逻辑） */
                Mortor_Turn();

                page = 0;
                sel  = 0;
                cnt  = 0;
                prev = -1;  /* 强制下次全刷新 */
            }
        }

        /* 动态数据更新（每次循环都刷新，不清屏） */
        if (page == 0) {
            OLED_ShowNum(48, 0,  temp, 2, 16, 1);
            OLED_ShowString(64, 0, "C", 16, 1);
            OLED_ShowNum(48, 16, humi, 2, 16, 1);
            OLED_ShowString(64,16, "%", 16, 1);
        }
        else if (page == 1) {
            for (i = 0; i < 4; i++) {
                u8 idx = i * 2, row = i * 16;
                u8 hl  = (idx == sel) ? 0 : 1;
                char line[17];
                int j, k = 0;
                /* 手工拼字符串 —— MicroLIB 不支持 %-8s */
                {
                    const char* s = names[i];
                    while (*s) line[k++] = *s++;
                }
                while (k < 9)  line[k++] = ' ';
                line[k++] = '$';
                line[k++] = '0' + price[idx];
                line[k++] = ' ';
                line[k++] = 'x';
                {
                    u8 q = inventory[idx];
                    if (q >= 10) { line[k++] = '0' + q/10; line[k++] = '0' + q%10; }
                    else         { line[k++] = '0' + q;    line[k++] = ' '; }
                }
                while (k < 16) line[k++] = ' ';
                line[16] = '\0';
                OLED_ShowString(0, row, (u8*)line, 16, hl);
            }
        }
        else if (page == 2) {
            OLED_ShowNum(48, 0,  sel,               2, 16, 1);
            OLED_ShowNum(56,16,  cnt,               2, 16, 1);
            OLED_ShowNum(64,32,  cnt * price[sel],  2, 16, 1);
        }

        /* ---- 定时上传数据到 OneNET ---- */
        if (upload == 1)
        {
            upload = 0;
            sprintf(json,
                "{\"id\":\"0\",\"version\":\"1.0\",\"params\":{"
                "\"temp\":{\"value\":%d},"
                "\"humi\":{\"value\":%d},"
                "\"Apple\":{\"value\":%d},"
                "\"Banana\":{\"value\":%d},"
                "\"Orange\":{\"value\":%d},"
                "\"Mango\":{\"value\":%d}"
                "}}",
                (int)temp, (int)humi,
                (int)inventory[0], (int)inventory[2],
                (int)inventory[4], (int)inventory[6]);

            ESP8266_UploadData(json);
        }

        OLED_Refresh();
        dms(50);  /* 主循环 ~20Hz */
    }
}

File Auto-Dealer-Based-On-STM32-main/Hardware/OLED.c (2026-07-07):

#include "stm32f10x.h"                  // Device header
#include "OLED.h"
#include "stdlib.h"
#include "OLED_Font.h"
#include "Delay.h"
#include "math.h"
#include "string.h"

u8 OLED_GRAM[144][8];

//反显函数
void OLED_ColorTurn(u8 i)
{
	if(i==0)
		{
			OLED_WR_Byte(0xA6,OLED_CMD);//正常显示
		}
	if(i==1)
		{
			OLED_WR_Byte(0xA7,OLED_CMD);//反色显示
		}
}

//屏幕旋转180度
void OLED_DisplayTurn(u8 i)
{
	if(i==0)
		{
			OLED_WR_Byte(0xC8,OLED_CMD);//正常显示
			OLED_WR_Byte(0xA1,OLED_CMD);
		}
	if(i==1)
		{
			OLED_WR_Byte(0xC0,OLED_CMD);//反转显示
			OLED_WR_Byte(0xA0,OLED_CMD);
		}
}

//延时
void IIC_delay(void)
{
	volatile u8 t = 8;    // 开漏模式，延时加长保证信号稳定
	while (t--) { __NOP(); }
}

//起始信号
void I2C_Start(void)
{
	OLED_SDA_Set();
	OLED_SCL_Set();
	IIC_delay();
	OLED_SDA_Clr();
	IIC_delay();
	OLED_SCL_Clr();
	IIC_delay();
}

//结束信号
void I2C_Stop(void)
{
	OLED_SDA_Clr();
	OLED_SCL_Set();
	IIC_delay();
	OLED_SDA_Set();
}

//等待信号响应
void I2C_WaitAck(void) //测数据信号的电平
{
	OLED_SDA_Set();
	IIC_delay();
	OLED_SCL_Set();
	IIC_delay();
	OLED_SCL_Clr();
	IIC_delay();
}

//写入一个字节
void Send_Byte(u8 dat)
{
	u8 i;
	for(i=0;i<8;i++)
	{
		if(dat&0x80)//将dat的8位从最高位依次写入
		{
			OLED_SDA_Set();
    }
		else
		{
			OLED_SDA_Clr();
    }
		IIC_delay();
		OLED_SCL_Set();
		IIC_delay();
		OLED_SCL_Clr();//将时钟信号设置为低电平
		dat<<=1;
  }
}

//发送一个字节
//mode:数据/命令标志 0,表示命令;1,表示数据;
void OLED_WR_Byte(u8 dat,u8 mode)
{
	I2C_Start();
	Send_Byte(0x78);
	I2C_WaitAck();
	if(mode){Send_Byte(0x40);}
  else{Send_Byte(0x00);}
	I2C_WaitAck();
	Send_Byte(dat);
	I2C_WaitAck();
	I2C_Stop();
}

//开启OLED显示 
void OLED_DisPlay_On(void)
{
	OLED_WR_Byte(0x8D,OLED_CMD);//电荷泵使能
	OLED_WR_Byte(0x14,OLED_CMD);//开启电荷泵
	OLED_WR_Byte(0xAF,OLED_CMD);//点亮屏幕
}

//关闭OLED显示 
void OLED_DisPlay_Off(void)
{
	OLED_WR_Byte(0x8D,OLED_CMD);//电荷泵使能
	OLED_WR_Byte(0x10,OLED_CMD);//关闭电荷泵
	OLED_WR_Byte(0xAE,OLED_CMD);//关闭屏幕
}

//更新显存到OLED	
void OLED_Refresh(void)
{
	u8 i,n;
	for(i=0;i<8;i++)
	{
		OLED_WR_Byte(0xb0+i,OLED_CMD); //设置行起始地址
		OLED_WR_Byte(0x00,OLED_CMD);   //设置低列起始地址
		OLED_WR_Byte(0x10,OLED_CMD);   //设置高列起始地址
		I2C_Start();
		Send_Byte(0x78);
		I2C_WaitAck();
		Send_Byte(0x40);
		I2C_WaitAck();
		for(n=0;n<128;n++)
		{
			Send_Byte(OLED_GRAM[n][i]);
			I2C_WaitAck();
		}
		I2C_Stop();
  }
}
//清屏函数
void OLED_Clear(void)
{
	u8 i,n;
	for(i=0;i<8;i++)
	{
	   for(n=0;n<128;n++)
			{
			 OLED_GRAM[n][i]=0;//清除所有数据
			}
  }
	OLED_Refresh();//更新显示
}

//画点 
//x:0~127
//y:0~63
//t:1 填充 0,清空	
void OLED_DrawPoint(u8 x,u8 y,u8 t)
{
	u8 i,m,n;
	i=y/8;
	m=y%8;
	n=1<<m;
	if(t){OLED_GRAM[x][i]|=n;}
	else
	{
		OLED_GRAM[x][i]=~OLED_GRAM[x][i];
		OLED_GRAM[x][i]|=n;
		OLED_GRAM[x][i]=~OLED_GRAM[x][i];
	}
}

//画线
//x1,y1:起点坐标
//x2,y2:结束坐标
void OLED_DrawLine(u8 x1,u8 y1,u8 x2,u8 y2,u8 mode)
{
	u16 t; 
	int xerr=0,yerr=0,delta_x,delta_y,distance;
	int incx,incy,uRow,uCol;
	delta_x=x2-x1; //计算坐标增量 
	delta_y=y2-y1;
	uRow=x1;//画线起点坐标
	uCol=y1;
	if(delta_x>0)incx=1; //设置单步方向 
	else if (delta_x==0)incx=0;//垂直线 
	else {incx=-1;delta_x=-delta_x;}
	if(delta_y>0)incy=1;
	else if (delta_y==0)incy=0;//水平线 
	else {incy=-1;delta_y=-delta_x;}
	if(delta_x>delta_y)distance=delta_x; //选取基本增量坐标轴 
	else distance=delta_y;
	for(t=0;t<distance+1;t++)
	{
		OLED_DrawPoint(uRow,uCol,mode);//画点
		xerr+=delta_x;
		yerr+=delta_y;
		if(xerr>distance)
		{
			xerr-=distance;
			uRow+=incx;
		}
		if(yerr>distance)
		{
			yerr-=distance;
			uCol+=incy;
		}
	}
}
//x,y:圆心坐标
//r:圆的半径
void OLED_DrawCircle(u8 x,u8 y,u8 r)
{
	int a, b,num;
    a = 0;
    b = r;
    while(2 * b * b >= r * r)      
    {
        OLED_DrawPoint(x + a, y - b,1);
        OLED_DrawPoint(x - a, y - b,1);
        OLED_DrawPoint(x - a, y + b,1);
        OLED_DrawPoint(x + a, y + b,1);
        OLED_DrawPoint(x + b, y + a,1);
        OLED_DrawPoint(x + b, y - a,1);
        OLED_DrawPoint(x - b, y - a,1);
        OLED_DrawPoint(x - b, y + a,1);
        
        a++;
        num = (a * a + b * b) - r*r;//计算画的点离圆心的距离
        if(num > 0)
        {
            b--;
            a--;
        }
    }
}



//在指定位置显示一个字符,包括部分字符
//x:0~127
//y:0~63
//size1:选择字体 6x8/6x12/8x16/12x24
//mode:0,反色显示;1,正常显示
void OLED_ShowChar(u8 x,u8 y,u8 chr,u8 size1,u8 mode)
{
	u8 i,m,temp,size2,chr1;
	u8 x0=x,y0=y;
	if(size1==8)size2=6;
	else size2=(size1/8+((size1%8)?1:0))*(size1/2);  //得到字体一个字符对应点阵集所占的字节数
	chr1=chr-' ';  //计算偏移后的值
	for(i=0;i<size2;i++)
	{
		if(size1==8)
			  {temp=asc2_0806[chr1][i];} //调用0806字体
		else if(size1==12)
        {temp=asc2_1206[chr1][i];} //调用1206字体
		else if(size1==16)
        {temp=asc2_1608[chr1][i];} //调用1608字体
		else if(size1==24)
        {temp=asc2_2412[chr1][i];} //调用2412字体
		else return;
		for(m=0;m<8;m++)
		{
			if(temp&0x01)OLED_DrawPoint(x,y,mode);
			else OLED_DrawPoint(x,y,!mode);
			temp>>=1;
			y++;
		}
		x++;
		if((size1!=8)&&((x-x0)==size1/2))
		{x=x0;y0=y0+8;}
		y=y0;
  }
}


//显示字符串
//x,y:起点坐标  
//size1:字体大小 
//*chr:字符串起始地址 
//mode:0,反色显示;1,正常显示
void OLED_ShowString(u8 x,u8 y,u8 *chr,u8 size1,u8 mode)
{
	while((*chr>=' ')&&(*chr<='~'))//判断是不是非法字符!
	{
		OLED_ShowChar(x,y,*chr,size1,mode);
		if(size1==8)x+=6;
		else x+=size1/2;
		chr++;
  }
}

//m^n
u32 OLED_Pow(u8 m,u8 n)
{
	u32 result=1;
	while(n--)
	{
	  result*=m;
	}
	return result;
}

//显示数字
//x,y :起点坐标
//num :要显示的数字
//len :数字的位数
//size:字体大小
//mode:0,反色显示;1,正常显示
void OLED_ShowNum(u8 x,u8 y,u32 num,u8 len,u8 size1,u8 mode)
{
	u8 t,temp,m=0;
	if(size1==8)m=2;
	for(t=0;t<len;t++)
	{
		temp=(num/OLED_Pow(10,len-t-1))%10;
			if(temp==0)
			{
				OLED_ShowChar(x+(size1/2+m)*t,y,'0',size1,mode);
      }
			else 
			{
			  OLED_ShowChar(x+(size1/2+m)*t,y,temp+'0',size1,mode);
			}
  }
}

int OLED_Count(int x) 
{
	int i = 0;
	while (x != 0)
	{
		x = x /10;
		i++;
	}
	return i;
}

void OLED_ShowDecNum(u8 x,u8 y,float num,u8 Declen,u8 size1,u8 mode)
{
	u8 t,temp,m=0;
	int integer = 0;
	int dec = 0;
	int integerLength = 0;
	float number = 0;
	number = num;
	integer = (int)num;
	dec = (number - integer) * pow(10,Declen);
	integerLength = OLED_Count(integer);
	if(size1==8)m=2;
	if(integerLength != 0)
	{
		for(t=0;t<integerLength;t++)
		{
			temp=(integer/OLED_Pow(10,integerLength-t-1))%10;
			if(temp==0)
			{
				OLED_ShowChar(x+(size1/2+m)*t,y,'0',size1,mode);
			}
			else 
			{
				OLED_ShowChar(x+(size1/2+m)*t,y,temp+'0',size1,mode);
			}
		}
		OLED_ShowChar(x+(size1/2+m)*t,y,'.',size1,mode);
		OLED_ShowNum(x+(size1/2+m)*(t+1),y,dec,Declen,size1,mode);
	}
	else
	{
		OLED_ShowChar(x,y,'0',size1,mode);
		OLED_ShowChar(x+(size1/2+m),y,'.',size1,mode);
		OLED_ShowNum(x+(size1/2+m)*2,y,dec,Declen,size1,mode);
	}	
}
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

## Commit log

2026-06-17 初始提交：完整硬件工程，含Keil源码、PCB源文件、Gerber、BOM物料清单
    [BOM_Board1_PCB1.xlsx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]
2026-06-17 优化README：移除ASCII框图，引用原理图图片，引脚表更清晰
2026-07-07 feat: 适配国产STM32F103芯片，修复编译烧录及硬件兼容问题
    - 烧录方式: 使用pyOCD+ST-Link替代Keil Flash Download(国产芯片ID校验不通过)
    - 延时函数: 用NOP循环替代SysTick Delay_ms(国产芯片SysTick异常)
    - 串口发送: fputc中USART_FLAG_TC改为USART_FLAG_TXE(国产芯片TC标志位卡死)
    - printf替换: ESP8266.c中printf全换为Serial_Printf
    - 蜂鸣器: 适配有源蜂鸣器(高电平响)
    - WiFi连接: 增加AT+CWQAP断开重连，超时从15s延长至20s
    - 时钟配置: 默认使用HSI 8MHz，修复SYSCLK_FREQ_72MHz未启用外部晶振时卡死
    - 中文字库: 更新OLED字库文件
    - 新增flash.ps1: PowerShell串口烧录备用脚本
    [BEEP.c, OLED.c, Serial.c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]
2026-07-07 更新README: 说明本次适配国产芯片改动
2026-07-07 fix: 重构MQTT通信+修复温湿度参数传反
    1. ESP8266驱动重构：放弃AT固件的MQTT指令(AT+MQTTUSERCFG等)，
    改用AT+CIPSEND发送原始MQTT报文(CONNECT/PUBLISH)，兼容性更好
    2. main.c修复：DHT11_Read_data调用参数顺序纠正(&humi在前、&temp在后)，
    修复温湿度显示互换的bug
    3. 更新.gitignore：排除.claude/和临时构建日志文件
    [main.c]
2026-07-08 feat: 整体重构UI+修复硬件问题+新增手机Web下单
    修复: LED_Init补全PA0~PA7全部8引脚(之前只初始化PA0导致灯不亮); 按键消抖从500ms改为20ms(修复按键不灵); 出货逻辑改为page状态机避免索引越界; 温湿度参数传反已修正
    重构: main.c用page状态机重写; OLED弃用中文字库改ASCII; ESP8266.c重写MQTT支持云端命令DISPENSE和库存改写; Serial改为累积缓冲; Upload新增Flash库存持久化
    新增: web/mobile.html手机Web下单页面, MQTT-over-WebSocket连接OneNET, 实时库存温湿度显示, 一键远程出货; LED_UpdateAll根据库存自动亮灭货道指示灯
    [LED.c, Serial.c, Upload.c]
2026-07-08 fix: 抽离硬编码凭据到外部文件，防止密钥泄露
    问题: ESP8266.c和mobile.html中硬编码了WiFi密码和OneNET MQTT签名，任何拿到源码的人都能远程控制售货机
    修复: 凭据移至secret.h(C)/secret.js(Web)，加入.gitignore; 仓库只保留.example模板文件，开发者复制后填入真实凭据即可
    影响文件: ESP8266.c引入secret.h宏; mobile.html优先加载secret.js(VENDING_SECRETS)，缺失则使用占位符可在⚙手动配置
2026-07-08 fix: 修复secret.h宏名与变量名冲突导致编译失败
    宏WIFI_SSID展开会替换变量名WIFI_SSID, 导致const char* WIFI_SSID = WIFI_SSID变成非法语句
    修复: 所有secret.h宏加SECRET_前缀(SECRET_WIFI_SSID等), 避免与ESP8266.c中同名变量冲突
2026-07-08 refactor: 手机页面改用OneNET HTTP API，弃用MQTT WebSocket
    MQTT WebSocket从浏览器连接OneNET不可用，改用REST API: HMAC-SHA1签名+fetch请求下发DISPENSE命令; 每15秒轮询设备数据刷新库存和温湿度; 配置面板增加API地址和AccessKey字段
2026-07-08 feat: 更新手机端下单功能，修复服务调用无法响应的问题
    - mobile.html: 改为通过本地 server.py 代理通信，无需浏览器直连 OneNET
    - server.py: 新增 Python HTTP 代理服务，使用 OneNET HTTP API 查询/下发
    - ESP8266.c: 新增显式订阅 4 路 DISPENSE 服务调用 topic，修复 MQTT 二进制解析
    - ESP8266.c: 新增 ESP8266_ServiceReply() 异步回复服务调用结果
    - main.c: 远程出货流程优化（先扣库存再驱动硬件），服务调用失败时正确回复
    - .gitignore: 新增 Python __pycache__/ 忽略规则
    [main.c]
2026-07-08 fix: 修复OneNET属性设置设备响应超时，云端可正常修改库存

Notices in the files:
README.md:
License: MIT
